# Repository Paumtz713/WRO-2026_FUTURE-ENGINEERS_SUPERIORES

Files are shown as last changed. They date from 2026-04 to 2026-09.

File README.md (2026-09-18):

# WRO 2026 Future Engineers Superiores
<p align="center">
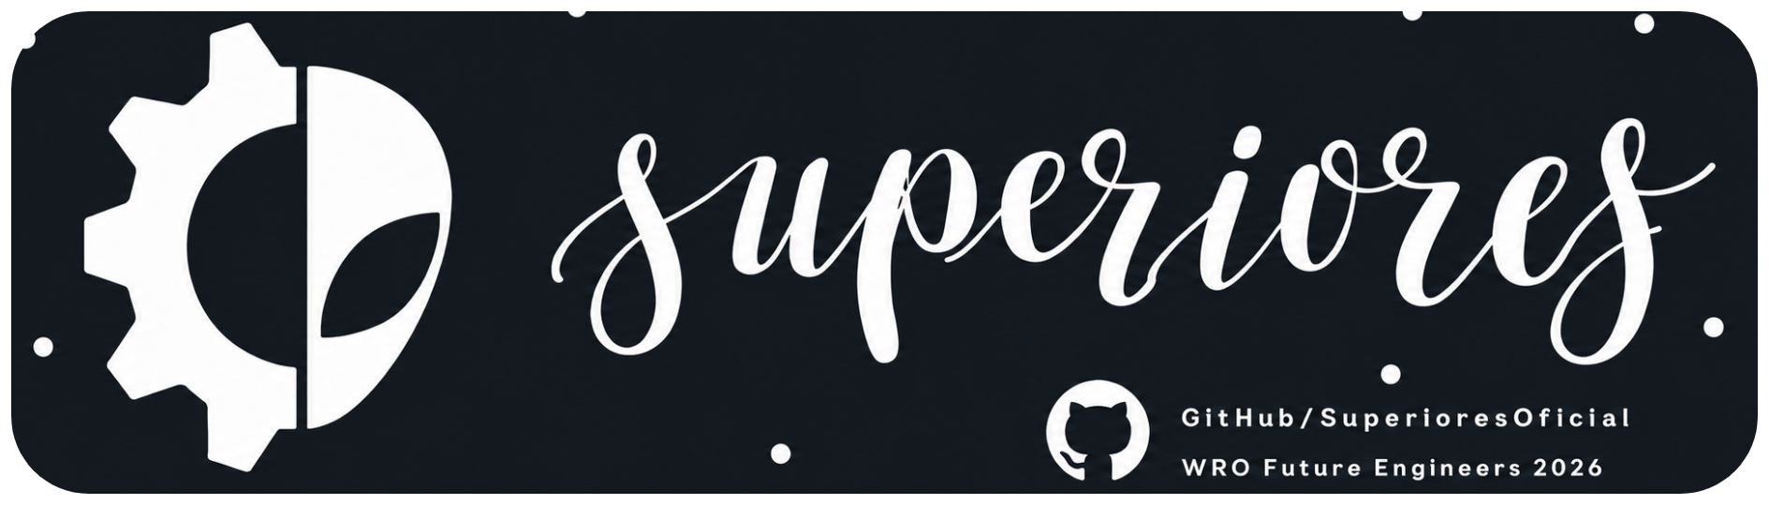
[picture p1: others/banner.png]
SUPERIORES
  
</p>

> [!NOTE]
> **Documentation Migration Notice**
> Due to an issue locating the main repository during the initial development phase, previous documentation and progress updates were temporarily tracked in a secondary repository. You can review the prior commits and documentation at the following link:
> https://github.com/daiilvvyeyo/WRO-2026-Future-Engineers-Superiores

<p align="center"> <a href="https://www.facebook.com/share/19RiiDTZch/"> Facebook </a> &nbsp;&nbsp;&nbsp; <a href="https://www.instagram.com/losgrisesrt/"> Instagram </a> &nbsp;&nbsp;&nbsp; <a href="https://www.tiktok.com/@losgrisesrobotics"> TikTok </a> </p>

## Team Members

#### Team photo

<p align="center">
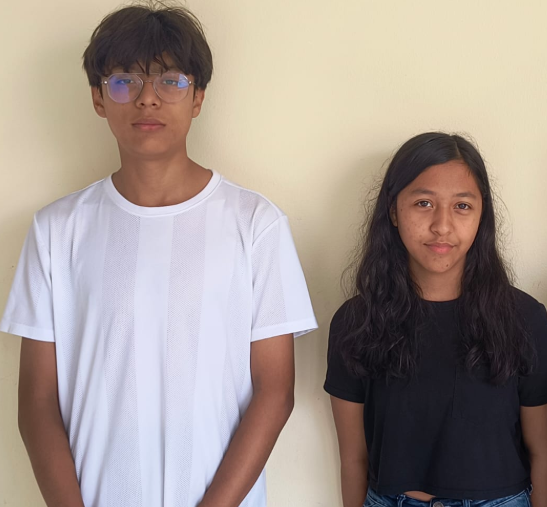
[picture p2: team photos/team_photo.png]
Foto de equipo
  
</p>

<table align="center">
  <tr>
    <th colspan="2" align="left">
      Eduardo Alvarado González — Coach & Founder
    </th>
  </tr>
  <tr>
    <td width="260">
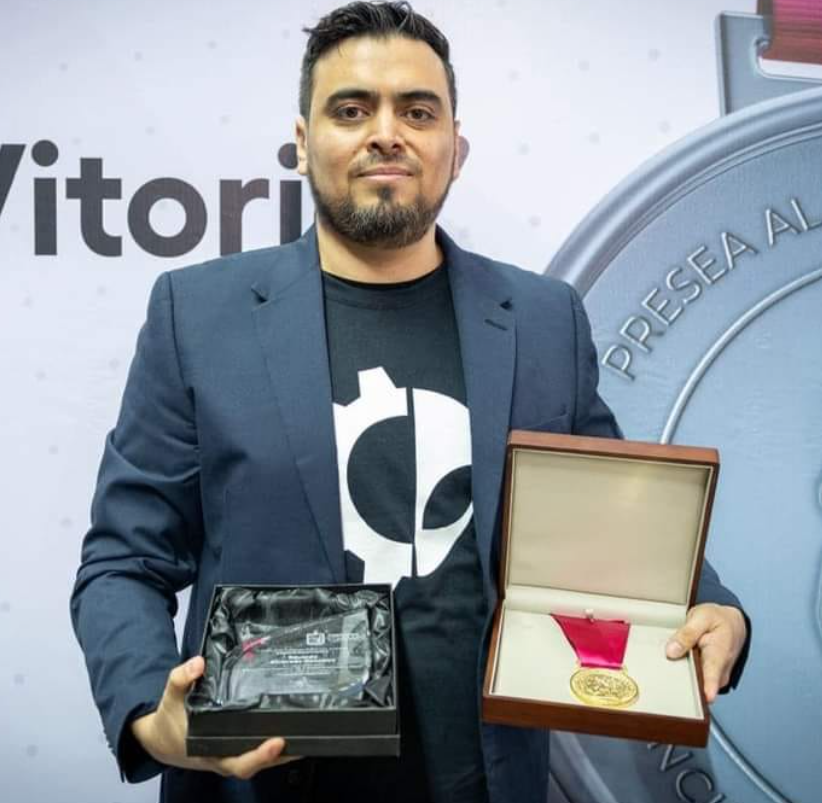
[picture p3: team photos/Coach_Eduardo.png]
      
    </td>
    <td>
      <b>Age:</b> 40<br><br>
      I founded <b>Los Grises Superiores</b> in 2014 with the goal of creating a team where students could learn engineering through real competition experience. Over the years we have participated in multiple WRO and TMR events, reaching both national and international stages. This season I mainly support the team in project organization, technical guidance, and helping the students improve their engineering process during development.
    </td>
  </tr>
</table>

---

<table align="center">
  <tr>
    <th colspan="2" align="left">
      Christopher Pérez Cortés — Programming & Electronics
    </th>
  </tr>
  <tr>
    <td width="260">
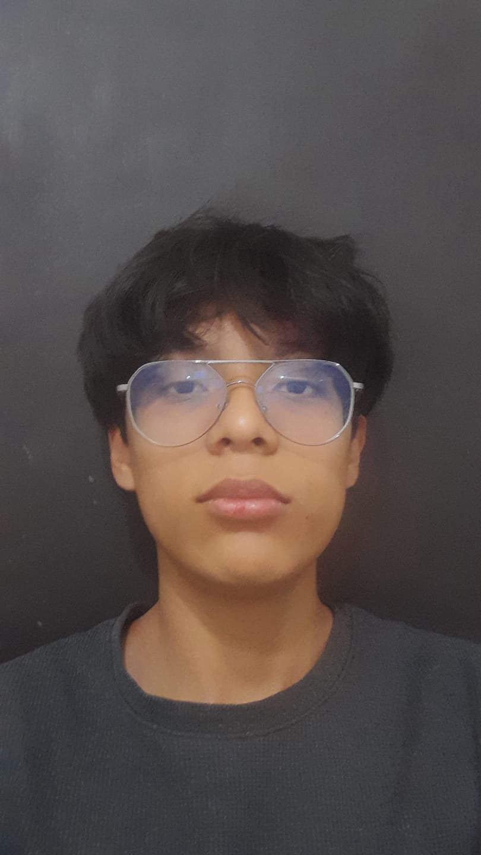
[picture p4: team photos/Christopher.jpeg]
      
    </td>
    <td>
      <b>Age:</b> 14<br><br>
      I joined the robotics club this year after taking an intensive robotics course, and since then I have been learning a lot about electronics, Arduino programming, and 3D design in Onshape. In the team I mainly work on the robot code, sensor integration, and electronics. WRO 2026 is my first international robotics competition, so this season has been a big learning experience for me.
    </td>
  </tr>
</table>

---

<table align="center">
  <tr>
    <th colspan="2" align="left">
      Bárbara Daiana García Balboa — Design & Assembly
    </th>
  </tr>
  <tr>
    <td width="260">
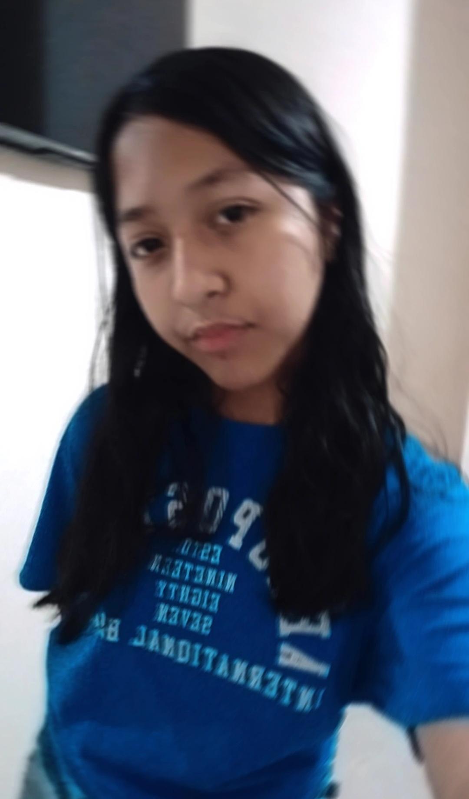
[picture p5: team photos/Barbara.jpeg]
      
    </td>
    <td>
      <b>Age:</b> 13<br><br>
      I joined the robotics club a few months ago after completing two robotics courses. My main role in the team is helping with the mechanical design, chassis assembly, and testing different structural ideas for the robot. This is my first robotics competition, so I have been learning how the engineering and competition process works while building the project together as a team.
    </td>
  </tr>
</table>

##  Track Challenges

* **Open Challenge:** Complete 3 full laps of the track in the shortest time possible while maintaining lane alignment using sensors (distance and vision).
* **Obstacle Challenge:** Navigate the track and dodge colored pillars in real time using computer vision (camera):
  * **Red Pillars:** Dodge by passing on the right.
  * **Green Pillars:** Dodge by passing on the left.
* **Autonomous Parking:** Detect the designated parking space and perform an automatic parallel parking maneuver upon completion.

## Project Videos

The following videos show the vehicle driving autonomously during both WRO Future Engineers 2026 challenges. Additional video documentation is available in the [video/](video/) folder.

<table>
  <tr>
    <th>Open Challenge</th>
    <th>Obstacle Challenge</th>
  </tr>
  <tr>
    <td align="center">
      <a href="https://www.youtube.com/watch?v=diX7vBUeAKw">
        
      </a>
    </td>
    <td align="center">
      <a href="https://www.youtube.com/watch?v=LjnSCSj2Bsk">
        
      </a>
    </td>
  </tr>
  <tr>
    <td align="center">
      <a href="https://www.youtube.com/watch?v=diX7vBUeAKw">Watch on YouTube</a>
    </td>
    <td align="center">
      <a href="https://www.youtube.com/watch?v=LjnSCSj2Bsk">Watch on YouTube</a>
    </td>
  </tr>
</table>

## Project Overview & Abstract

This project was developed as the evolution of our 2025 WRO Future Engineers robot, which successfully reached the international final. Based on the experience gained during that season, the entire vehicle was redesigned for 2026 using a fully 3D-printed chassis, an OpenMV H7 camera, and an Arduino Nano-based control system to improve stability, adaptability, and overall performance.

The robot was built to autonomously complete the two Future Engineers challenges established by the WRO 2026 rules. During the Open Challenge, the vehicle must complete three laps while adapting to randomized track conditions such as driving direction, starting position, and corridor width. In the Obstacle Challenge, the robot must detect colored traffic pillars, avoid them from the correct side, and finally perform a parallel parking maneuver inside the designated parking zone.

Throughout the development process, the team continuously tested and improved both the mechanical and software systems in order to adapt the robot to the new 2026 rule changes and achieve more reliable autonomous behavior.

### Chassis Design & Iteration 

Our first robot designs were based on a LEGO Mindstorms EV3 chassis. While it was easy to build and modify, we noticed several limitations during testing, especially related to weight, space distribution, and steering precision. The EV3 structure was also too restrictive for the type of custom design we wanted to achieve for the 2026 season.

Because of this, we decided to redesign the entire chassis using fully 3D-printed parts designed in Onshape. Our main goal was to create a lighter and more compact structure while still following the WRO size and weight regulations. We also wanted to improve stability, steering performance, and sensor placement.

Throughout the season, we tested different chassis versions. The first prototype used a flat structure, but during steering tests we discovered that the chassis flexed when the servo applied force, causing inaccurate steering movements. To improve rigidity, we redesigned the structure by adding reinforced supports and increasing the wall thickness in critical areas.

Later, we developed a third version focused on improving cornering performance in the new 600 mm corridor introduced in the 2026 rules. We reduced the overall length of the robot and relocated some electronic components to lower the center of gravity and improve balance while turning.

During the final reprint of the chassis using grey PLA filament, we encountered an unexpected problem: the drivetrain became stuck even though the motor was working correctly. After inspecting the structure, we realized that the new filament produced slightly tighter tolerances, causing friction around the rear axle housing. To solve this, we manually sanded the affected area until the shaft rotated smoothly again. After this issue, we started checking all moving parts after every print before assembling the robot.

### Steering System

The robot uses an **Ackermann steering geometry** controlled by a rack-and-pinion mechanism. The steering system was developed through several iterations during the prototyping process.

In the previous prototype, we used a **Steren MOT-110 micro servo** to control the steering mechanism. This version allowed us to test the basic steering geometry and evaluate the mechanical response of the system.

For the final vehicle, we decided to use an **SG90 micro servo**. The SG90 was selected for the final version because it provided the required steering movement while being compact and easy to integrate into the redesigned chassis.

The servo is connected to a **LEGO Technic rack-and-pinion mechanism (part 64781)**, which converts the servo's rotational movement into the linear movement required to turn the front wheels.

The steering system follows **Ackermann geometry**, allowing the inner and outer front wheels to turn at different angles during a corner. This helps the vehicle maintain a more appropriate trajectory while navigating the track.

The final steering configuration consists of:

* **Servo motor:** SG90 micro servo
* **Steering mechanism:** Rack-and-pinion
* **Rack:** LEGO Technic part 64781
* **Steering geometry:** Ackermann
* **Control:** Arduino Nano

 ## Robot Photos

| Front | Back | Left |
|:---:|:---:|:---:|
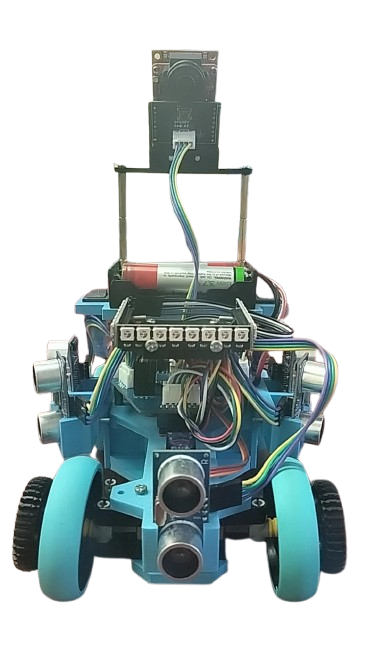
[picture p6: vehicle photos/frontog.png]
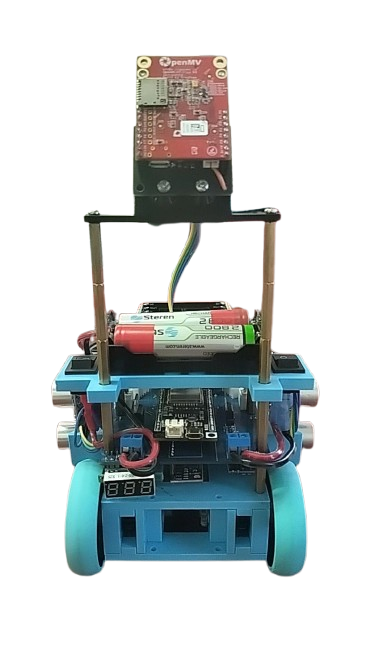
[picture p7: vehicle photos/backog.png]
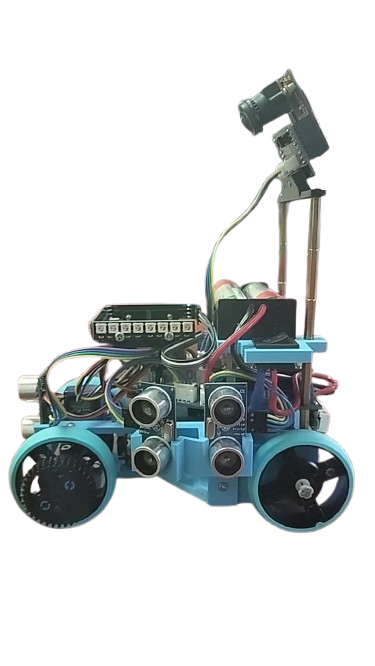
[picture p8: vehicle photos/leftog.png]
|  |  |  |

| Right | Top | Bottom |
|:---:|:---:|:---:|
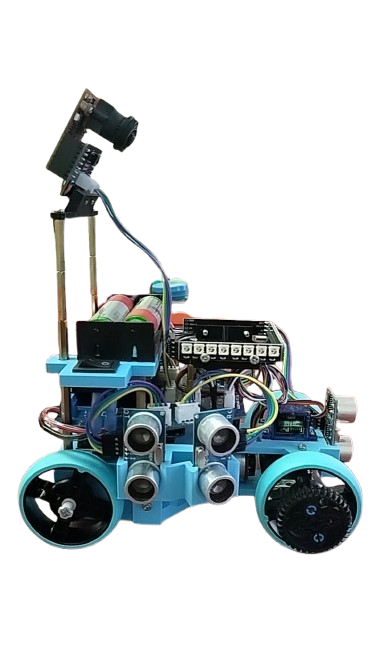
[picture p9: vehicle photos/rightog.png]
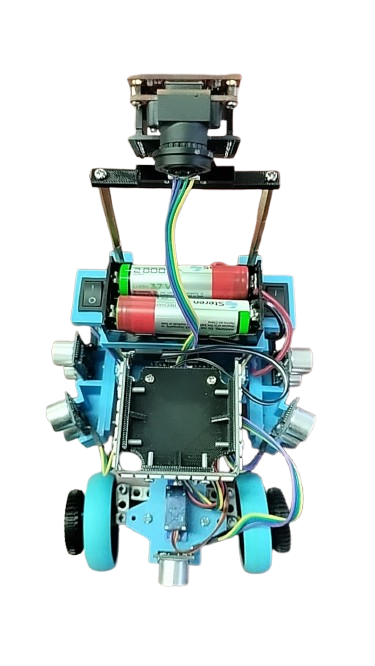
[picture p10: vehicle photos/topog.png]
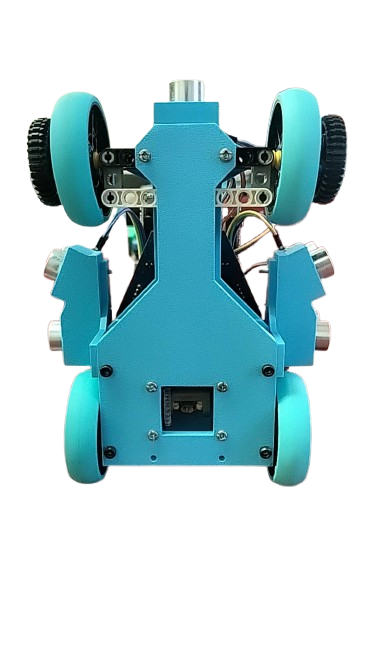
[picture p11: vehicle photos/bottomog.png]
|  |  |  |

- Robot Weight: 0.710 kg

## Robot 360º

<p align="center">
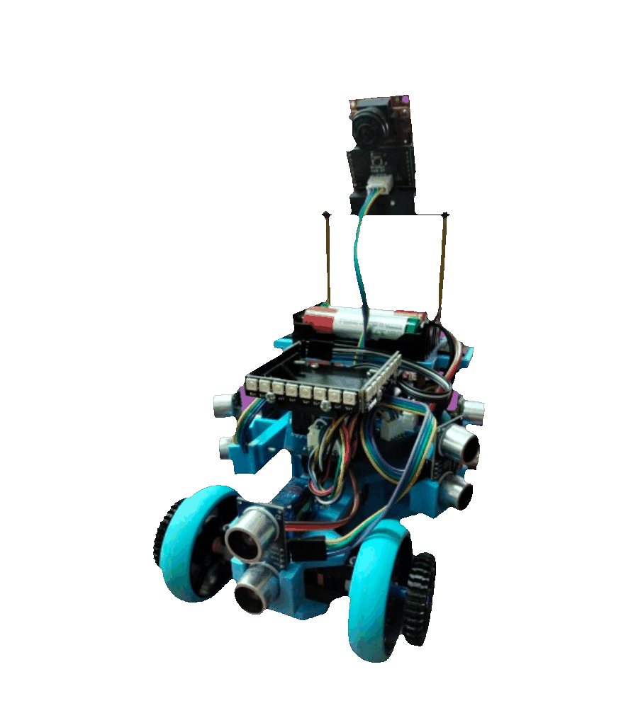
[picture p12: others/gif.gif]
Robot 360º
  
</p>

## Robot Components

| Component | Quantity | Main Function |
|---|:---:|---|
| ESP32 Microcontroller | 1 | Main processing / communication with OpenMV and sensors |
| Arduino Nano Microcontroller | 1 | Additional control (motor, encoders, ultrasonic sensors) |
| OpenMV Camera | 1 | Color vision, RX/TX communication (UART) |
| BNO085 IMU | 1 | Orientation / yaw (I2C: SCL, SDA) |
| HC-SR04 Ultrasonic Sensor | 5 | Distance measurement (front, 2 left, 2 right) |
| TB6612FNG Motor Driver | 1 | H-bridge for controlling the DC motor (PWMA, AIN1, AIN2, STBY) |
| DC Motor with Encoder | 1 | Traction (uses ENC_A and ENC_B for speed feedback) |
| 4-Channel Logic Level Converter | 1 | Adapts 3.3V ↔ 5V signals between modules (HV/LV x4) |
| Steering Servo | 1 | Steering control (S1 signal, SER_5+ power supply) |
| NeoPixel LEDs (WS2812) | 1 strip | Indicator lighting / vision assistance |
| 18650 Battery | Several | Main power supply (power bank) |
| Mini-560 Buck Converter | 2 | Voltage regulation (one line to 5V, another to 3.3V) |
| 7805 Voltage Regulator | 2 | One for the servo (SER_5+), another for the LEDs (LEDS_5+) |
| Digital Voltmeter | 1 | Battery voltage monitoring |

## Code

Our robot uses two main programs that work together. The Arduino Nano handles the distance sensors and LED strips, while the ESP32 acts as the main controller of the robot.

### Sensor Codes

- [ESP32 Open Optimized](./ESP32_Open_Optimizado.ino) — Main control code that processes the sensor data and manages the robot's movement.

- [Nano Sensors I2C 3x8](./Nano_Sensors_I2C_3x8.ino) — Reads the ultrasonic sensors through I2C and sends distance measurements to the ESP32.

- [Obstacle & Parking Exit](./OBSTACULOS_Salida_del_parking.ino) — Controls obstacle detection and the sequence used to exit the initial parking area.
### Arduino Nano — Sensors & LEDs

The Arduino Nano works as an assistant to the ESP32. It measures the five ultrasonic sensors, controls three strips of eight LEDs, and communicates the sensor measurements to the ESP32 through I2C.

### OpenMV – Detección y visión

[Detección de pilares, parking y obstáculos](./codes/color_corner_v6.py)  
Sistema de visión de la OpenMV encargado de detectar pilares rojos y verdes, identificar las paredes y el hueco del estacionamiento, detectar posibles colisiones y enviar los datos al ESP32 mediante UART. :contentReference[oaicite:0]{index=0}

[Explicación del código](./codes/Pegado%20text(1).txt)  
Explicación detallada del funcionamiento del sistema de visión, sus ROI, filtros de color y forma, detección del parking y comunicación con el ESP32. :contentReference[oaicite:1]{index=1}

**Main functions:**

* Reads five ultrasonic distance sensors.
* Controls 24 LEDs arranged in three strips of eight.
* Sends distance measurements to the ESP32.
* Receives the LED intensity level from the ESP32.
* Uses I2C communication at address `0x08`.

[View Arduino Nano Code](./codes/Nano_Sensores_I2C_3x8.ino)

### ESP32 — Main Robot Control

The ESP32 is the main controller of the robot. It receives the distance measurements from the Arduino Nano and uses them to control the motor, steering, speed, safety systems, lap counting, and final parking sequence.

**Main functions:**

* Receives data from the five distance sensors.
* Controls the DC motor through the TB6612FNG.
* Controls the SG90 steering servo.
* Uses the BNO085 to track orientation and count three laps.
* Uses the encoder to detect actual wheel movement.
* Maintains the robot centered using PID control.
* Detects walls and corners.
* Adjusts speed according to track conditions.
* Performs emergency reverse maneuvers.
* Executes the final movement after completing three laps.
* Provides an optional Wi-Fi dashboard for monitoring the robot.

[View ESP32 Code](./codes/ESP32_Open_Optimizado.ino)

# LEGO Set Use

| BLItemNo | ElementId | LdrawId | Part Name | BLColorId | LDrawColorId | Color Name | Qty | Weight (g) | Price per piece (USD) | Total (USD) |
|---|---|---|---|---|---|---|-----|---|---|---|
| 6589 | 4565452 | 6589.dat | Technic Gear 12 Tooth Bevel | 19 | 19 | Tan | 3 | 0.40 | 0.15 | 0.45 |
| 3713 | 6275844 | 3713.dat | Technic Bush | 86 | 7 | Light Bluish Gray | 6 | 0.20 | 0.05 | 0.30 |
| 32523 | 4142822 | 32523.dat | Technic Liftarm 1 x 3 | 11 | 0 | Black | 2 | 0.80 | 0.20 | 0.40 |
| 39367pb01 | 6460453 | 39367.dat | Wheel 56 x 14 Technic | 102 | 9 | Blue | 4 | 5.50 | 1.50 | 6.00 |
| 62821b | — | 62821.dat | Technic Differential Gear (Closed) | 85 | 8 | Dark Bluish Gray | 1 | 3.50 | 3.50 | 3.50 |
| 87083 | 6083620 | 87083.dat | Technic Axle 4L with Stop | 85 | 8 | Dark Bluish Gray | 4 | 0.60 | 0.10 | 0.40 |
| 94925 | 4640536 | 94925.dat | Technic Gear 16 Tooth | 86 | 7 | Light Bluish Gray | 4 | 0.50 | 0.20 | 0.80 |
| 43093 | — | 43093.dat | Technic Axle 1L with Pin | 102 | 9 | Blue | 2 | 0.30 | 0.15 | 0.30 |
| 43093 | — | 43093.dat | Technic Axle 1L with Pin | 19 | 19 | Tan | 2 | 0.30 | 0.15 | 0.30 |
| 48989 | 6282158 | 48989.dat | Technic Pin Connector Perpendicular 3L | 86 | 7 | Light Bluish Gray | 2 | 1.00 | 0.30 | 0.60 |
| 40490 | 4645732 | 40490.dat | Technic Liftarm 1 x 9 | 15 | 15 | White | 1 | 1.20 | 0.50 | 0.50 |
| 32523 | 4142822 | 32523.dat | Technic Liftarm 1 x 3 | 11 | 0 | Black | 2 | 0.80 | 0.20 | 0.40 |
| 4265c | 6271167 | 4265c.dat | Technic Bush 1/2 Smooth | 3 | 14 | Yellow | 2 | 0.10 | 0.10 | 0.20 |

| TOTAL PARTS | TOTAL WEIGHT |
|---|---|
| 35 | 39.2 g |

### Traction System

For the traction system, we decided to use a rear-wheel drive configuration powered by a DC motor with an integrated gearbox connected to a TB6612FNG motor driver. Both rear wheels are connected through the same drivetrain, which helped us keep the system simpler, lighter, and fully compliant with the WRO rules.

During testing, we experimented with different gear ratios to find the best balance between speed and control. Some configurations made the robot extremely fast, but that also reduced the reaction time when detecting obstacles or correcting direction. Other configurations improved stability but made the robot too slow during acceleration.

After multiple test sessions, we found that an approximate 1:30 gear ratio gave us the best overall performance for both challenges.

| Parameter | Value |
|---|---|
| Drive motor | DC motor with gearbox |
| Motor driver | TB6612FNG dual H-bridge |
| Drive system | Rear-wheel drive |
| Wheel configuration | Both rear wheels connected together |
| Selected gear ratio | Approx. 1:30 |

### Speed Testing

| PWM Value | Approx. Speed | Main Use |
|---|---|---|
| 110 | ~0.28 m/s | Narrow corridor and obstacle sections |
| 130 | ~0.36 m/s | Normal track navigation |
| 150 | ~0.44 m/s | Open straight sections |

### Gear Ratio Comparison

| Gear Ratio | What Happened |
|---|---|
| 1:20 | The robot became too fast and reacted late to obstacles |
| 1:50 | Acceleration became too slow for completing laps efficiently |
| 1:30 | Best balance between speed, control, and stability |

#### Mechanical Trade-offs & Decisions

During the development process, we tested different ideas and components before deciding on the final configuration of the robot. In several cases, we had to choose between simplicity, performance, reliability, and compliance with the WRO rules.

| System | Option We Chose | Option We Rejected | Why We Chose It |
|---|---|---|---|
| Chassis material | 3D-printed PLA | LEGO Technic | Allowed us to create custom shapes while reducing overall weight |
| Steering system | Servo + rack mechanism | Differential steering | More stable and compliant with WRO steering rules |
| Drive system | Single DC motor | Two coupled motors | Simpler wiring, lighter structure, and easier control |
| Vision system | OpenMV H7 (UART) | HuskyLens (I2C) | OpenMV provided faster and more stable data during movement |

One of the most important decisions was replacing the HuskyLens camera with the OpenMV H7. During testing, we noticed that the HuskyLens sometimes sent data too slowly, which caused unstable steering corrections and servo oscillation. After switching back to the OpenMV system, the robot behaved much more smoothly and consistently during autonomous navigation.**

## Final Robot Design

<p align="center">
  <a href="./models/final_design.stl">
    Final 3D Design of Superiores Robot
  </a>
</p>

<p align="center">
  <b>Final 3D chassis design — WRO 2026 Future Engineers</b><br>
  Click the image to open the complete STL model.
</p>

### Why We Chose This Design

The final chassis was selected after several mechanical iterations and testing sessions throughout the development of our WRO 2026 robot.

Our first prototypes were based on LEGO Technic and EV3 components. Although this approach made early modifications easier, it introduced several limitations, including higher weight, less freedom in component placement, chassis flex, and a larger overall structure.

For the final version, we designed a custom 3D-printed chassis in Onshape. This allowed us to control the geometry of the robot and place each mechanical and electronic component according to its function.

The final design was chosen mainly for the following reasons:

- **Compact dimensions:** A shorter chassis improves maneuverability and reduces the turning radius, which is especially important in the narrower sections of the WRO 2026 track.

- **Improved steering rigidity:** Earlier versions flexed when the steering servo applied force. The final chassis includes reinforced structural areas to reduce deformation and make the Ackermann steering system more precise.

- **Better component distribution:** The ESP32, Arduino Nano, motor driver, batteries, OpenMV camera, ultrasonic sensors, BNO085 and other electronics can be positioned in specific locations instead of being limited by a LEGO structure.

- **Lower center of gravity:** Heavy components were positioned as low as possible to improve stability while turning and during obstacle avoidance maneuvers.

- **Sensor positioning:** The custom structure provides dedicated mounting positions for the front and lateral ultrasonic sensors, allowing the robot to measure the walls and obstacles from consistent angles.

- **Camera visibility:** The front section was designed so the OpenMV camera has a clear field of view for detecting red and green pillars as well as the parking area.

- **Ackermann steering integration:** The chassis was designed around the steering mechanism instead of adapting the steering mechanism to an existing chassis. This provides better alignment between the servo, rack-and-pinion system and front wheels.

- **Rear-wheel-drive integration:** The rear section provides the necessary space and alignment for the DC motor, drivetrain and rear axle while keeping the propulsion system compact.

- **Easy maintenance:** The open and modular structure allows us to access the electronics, sensors and mechanical components quickly during testing and competition.

- **Iterative manufacturing:** Because the chassis is 3D printed, individual parts can be redesigned and reprinted when a problem is discovered without rebuilding the entire robot.

The objective of the final design was not simply to make the robot smaller or lighter. We wanted the mechanical structure, electronics, sensors and software to work together as a single system.

This design represents the lessons learned from our previous prototypes and provides a better balance between **stability, maneuverability, sensor coverage, steering precision, accessibility and reliability** for the WRO 2026 Future Engineers challenges.

### 3D Model

The complete printable model is available here:

 **[Open `final_design.stl`](./models/final_design.stl)**

####  Structural Components (3D Design) 

<div align="center">

| Central Sensor Mount | Side Sensor Mounts | Rear Support |
|:--:|:--:|:--:|
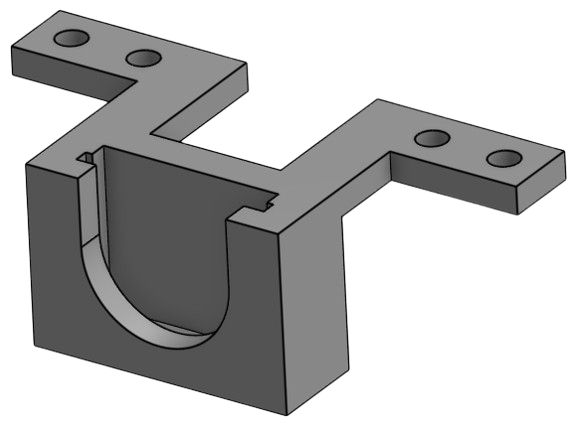
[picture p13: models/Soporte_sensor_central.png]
Central Sensor Mount
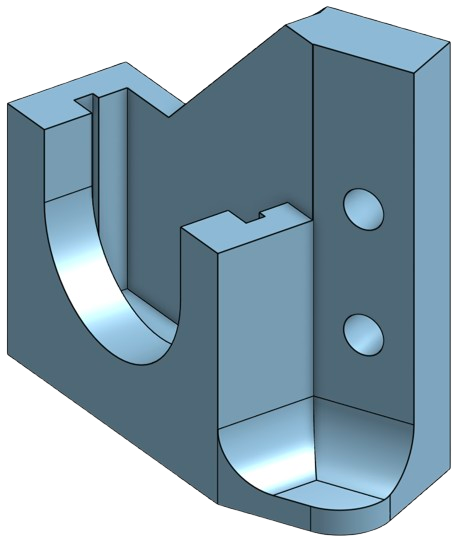
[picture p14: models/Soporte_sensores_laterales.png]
Side Sensor Mounts
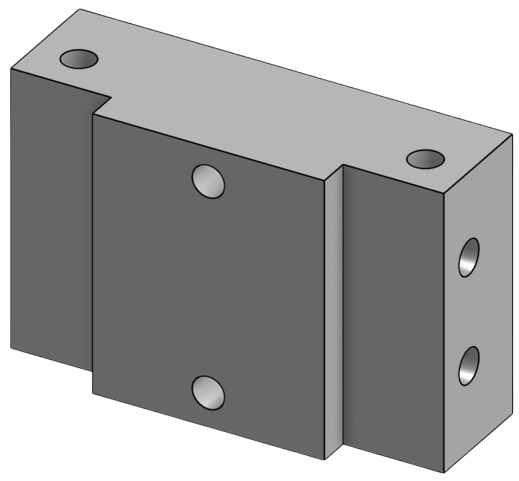
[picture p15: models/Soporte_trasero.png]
Rear Support
|  |  |  |

| External Supports | Internal Supports | Directional Module |
|:--:|:--:|:--:|
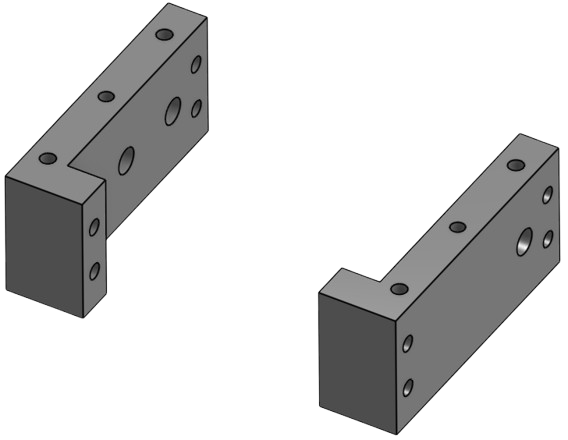
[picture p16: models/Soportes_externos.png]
External Supports
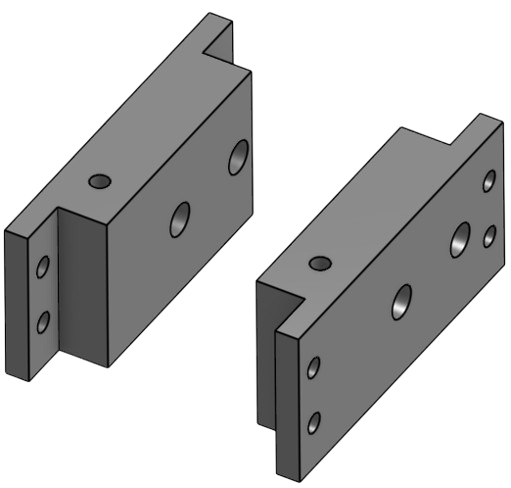
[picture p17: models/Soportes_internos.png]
Internal Supports
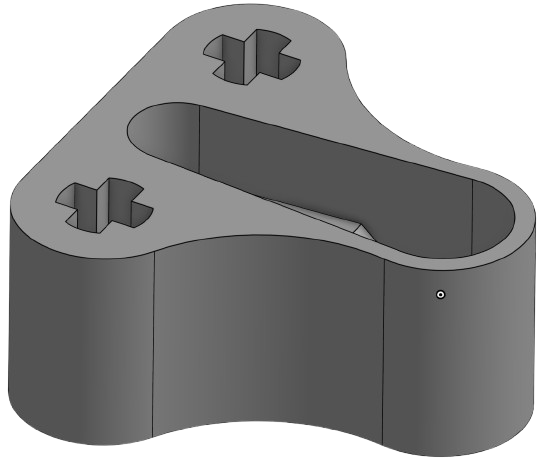
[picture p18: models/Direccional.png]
Directional Module
|  |  |  |

| Lower Body | Upper Body | Full Base Structure |
|:--:|:--:|:--:|
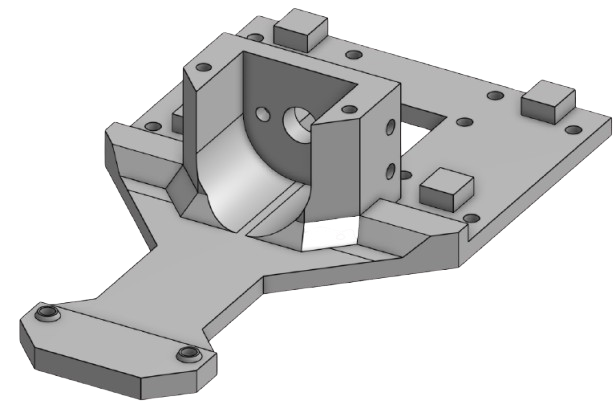
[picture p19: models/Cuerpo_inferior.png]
Lower Body
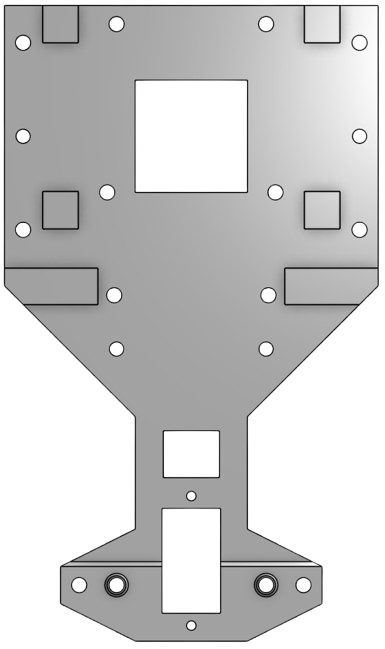
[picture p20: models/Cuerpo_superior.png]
Upper Body
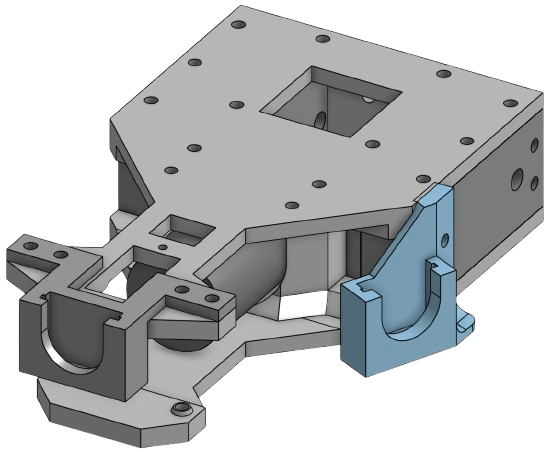
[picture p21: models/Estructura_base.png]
Full Base Structure
|  |  |  |

</div>

---

| Main Switch | 1 | Motor / system power cutoff |
| 2P Terminal Block | 1 | Power input (7.4V+) |

####  Main Chassis Structure

<div align="center">

| Lower Body | Upper Body |
|:--:|:--:|
|  |  |

</div>
---

####  Complete Aseembly

<div align="center">

| Full Base Structure |
|:--:|
|  |

</div>

---

####  Steering Component

<div align="center">

| Directional Module |
|:--:|
|  |

</div>
---

## PCB & Wiring Implementation

<table>
  <tr>
    <td align="center" width="50%">
      <strong>PCB Design</strong><br><br>
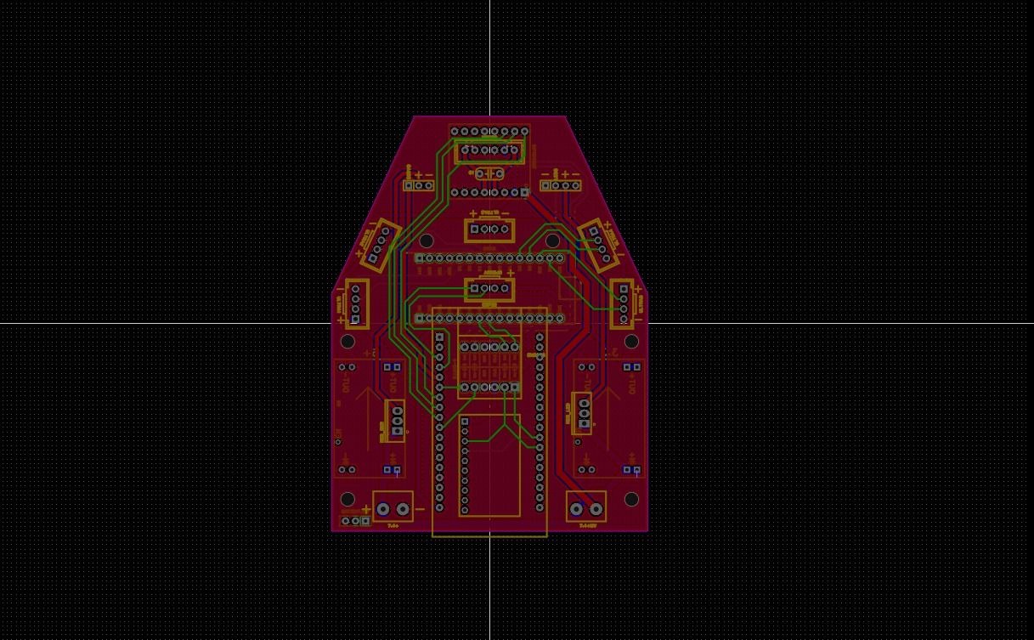
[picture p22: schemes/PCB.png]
      
    </td>
    <td align="center" width="50%">
      <strong>Real PCB</strong><br><br>
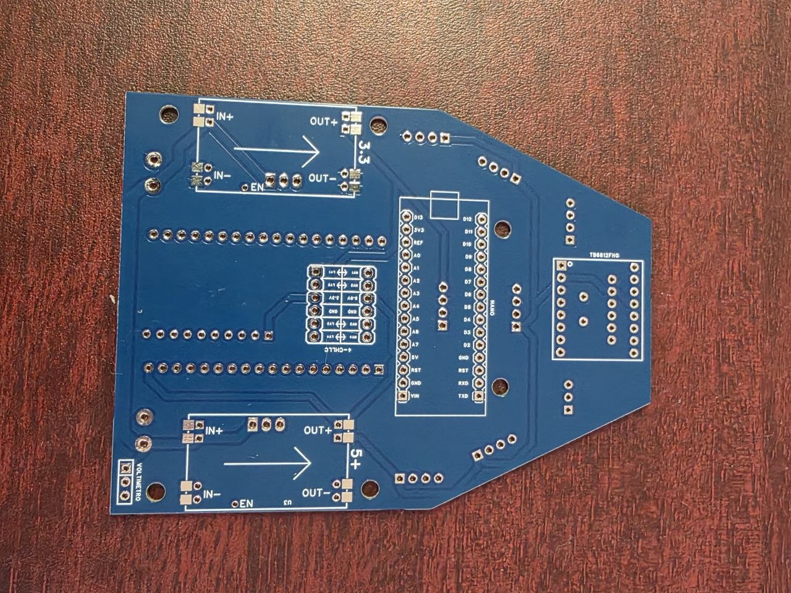
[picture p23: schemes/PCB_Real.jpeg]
      
    </td>
  </tr>
  <tr>
    <td colspan="2" align="center">
      <strong>PCB Schematic</strong><br><br>
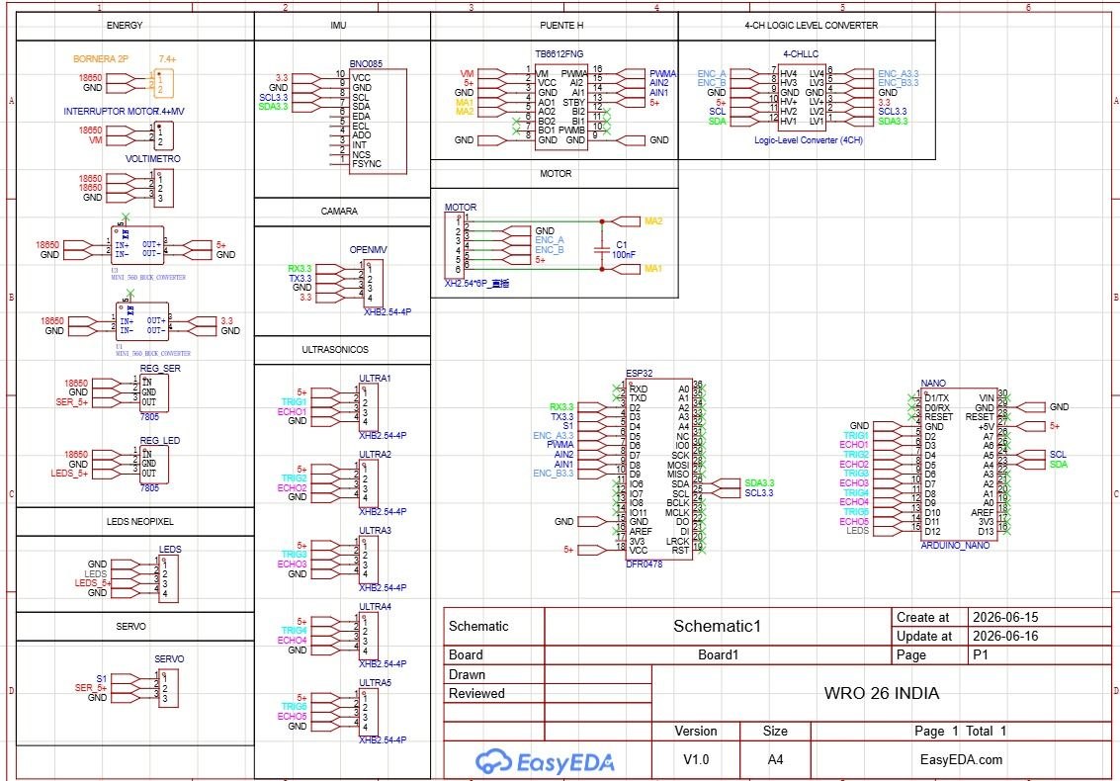
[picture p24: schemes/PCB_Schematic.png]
      
    </td>
  </tr>
</table>

## Source Code

Full source code available in `src/`

Our robot is controlled using an Arduino Nano, where we manage sensor reading, steering control, obstacle reactions, and movement decisions. Throughout the season, we continuously tested and adjusted the code to improve stability and response time during both challenges.

Some of the main functions implemented in our code include:

- Ultrasonic-based wall navigation
- IMU yaw tracking and lap counting
- OpenMV color detection for red and green pillars
- Obstacle avoidance logic
- Parking sequence development

# Criterion 2 — Power & Sensor Architecture

## Power System & Budget

To power the robot, we use two Steren Li-ion 3.7V batteries connected in series, providing a total of 7.4V. We separated the power system into two rails: one dedicated to the electronic components and another one for the motor system. This helped us reduce electrical noise and achieve more stable sensor readings during movement.

| Rail | Components Powered | Estimated Consumption |
|---|---|---|
| 5V Logic Rail | Arduino Nano, MPU6050, OpenMV H7, HC-SR04 sensors | ~600 mA |
| Motor Rail | TB6612FNG + DC motor | ~1.5 A |

We used a Mini 560 step-down regulator to provide a stable 5V supply for the electronic components. During testing, this configuration proved reliable even when the motor rapidly changed speed.

One issue we considered was battery voltage drop during long testing sessions. When the voltage became too low, the robot started losing motor performance and sensor stability. Because of this, we added a small digital voltmeter directly on the chassis to monitor battery voltage before every run.

## Ultrasonic Sensor Expansion

During early testing with 3 sensors, we noticed that the robot couldn't measure distances accurately enough to maintain precise wall centering. To solve this and improve spatial awareness, we upgraded our setup to 5 HC-SR04 ultrasonic sensors: 2 on the right side, 2 on the left side, and 1 in the front center.

| Sensor | Position | Purpose |
| --- | --- | --- |
| Front | Front center | Detect walls and corners ahead |
| Left (×2) | Left side | Measure distance and alignment to left wall |
| Right (×2) | Right side | Measure distance and alignment to right wall |
### Power Consumption

| Component | Approx. Current |
|---|---|
| Arduino Nano | 20 mA |
| MPU6050 | 3.9 mA |
| OpenMV H7 | ~280 mA |
| HC-SR04 ×5 | ~75 mA |
| Steering Servo | ~200 mA |
| DC Motor | 800–1500 mA |

## Wiring Diagram

Full wiring diagrams available in `schemes/`

The electrical system was designed to keep the wiring as organized and compact as possible inside the chassis. Most components are connected directly to the Arduino Nano and distributed through the PCB designed by the team.

### Main Connections

| Component | Connection |
|---|---|
| MPU6050 | SDA → A4 / SCL → A5 |
| OpenMV H7 | UART TX/RX |
| Front Ultrasonic | TRIG → D7 / ECHO → D6 |
| Left Ultrasonic | TRIG → D3 / ECHO → D2 |
| Right Ultrasonic | TRIG → D5 / ECHO → D4 |
| DC Motor Driver | AIN1 → D10 / AIN2 → D11 / PWMA → D9 |
| Steering Servo | Signal → D8 |

The MPU6050 communicates through I2C, while the OpenMV camera uses UART communication. This allowed us to keep the I2C bus dedicated only to the IMU and helped improve communication stability between modules.

## PCB & Iteration Problems

To keep the internal wiring cleaner and more organized, we designed a custom PCB to centralize all the electrical connections inside the robot. Compared to direct wiring, this helped us reduce cable clutter, simplify debugging, and improve overall reliability during movement.

During one of our testing sessions, we accidentally inserted the batteries backward into the power rail. This reverse polarity connection caused the Li-ion battery to short-circuit and emit smoke due to thermal overload. 

Fortunately, none of our main sensors or microcontrollers suffered permanent damage. However, to prevent potential trace degradation or instability in the power lines, we solved this issue by replacing the damaged board with a spare custom PCB we already had available.

Additionally, during our first PCB assembly, excess solder created small bridges between nearby PCB traces, causing interference between the TRIG and ECHO signals of the sensors. We solved this by removing the excess solder with desoldering braid and re-soldering the affected areas. Once cleaned, the readings stabilized completely.

## Sensor Selection & Placement

### HC-SR04 Ultrasonic Sensors

During early testing with 3 sensors, we noticed that the robot couldn't measure distances accurately enough to maintain precise wall centering. To solve this and improve spatial awareness, we upgraded our setup to 5 HC-SR04 ultrasonic sensors: 2 on the right side, 2 on the left side, and 1 in the front center.

| Sensor | Position | Purpose |
| --- | --- | --- |
| Front | Front center | Detect walls and corners ahead |
| Left (×2) | Left side | Measure distance and alignment to left wall |
| Right (×2) | Right side | Measure distance and alignment to right wall |

### MPU6050 IMU

The MPU6050 is used mainly for yaw tracking and orientation correction. We use the gyroscope data to count turns, detect drift, and calculate completed laps during autonomous navigation.

Some of the main functions of the IMU in our robot are:

- Counting 90° turns
- Correcting drift on straight sections
- Determining lap completion through accumulated yaw

Before every run, the robot performs a short calibration process while remaining completely still. This allows the IMU to calculate sensor offsets and improve accuracy during movement.

### Camera — OpenMV H7

For vision processing, we currently use an OpenMV H7 camera connected through UART communication.

| Parameter | Value |
|---|---|
| Resolution | 320 × 240 px |
| Communication | UART (115200 baud) |
| Detection Mode | Color blob tracking |
| Objects Detected | Red and green pillars |
| Frame Rate | ~30 FPS |
| Camera Position | Front-center, tilted downward |

At the beginning of the season, we originally planned to use a HuskyLens camera because it was easier to integrate and already included built-in object detection features. However, during testing we discovered that the HuskyLens was sending data too slowly for our steering system.

Because the Arduino was not receiving continuous detection updates, the steering servo started oscillating and the robot moved inconsistently during straight sections.

To solve this problem, we switched back to the OpenMV H7 platform that we had already used during the 2025 season. Using a custom MicroPython script, the OpenMV continuously sends detection data to the Arduino through UART communication, resulting in much smoother and more stable steering behavior.

Although the OpenMV required more programming and communication handling, the improvement in reliability and response time made the change completely worth it.

After several tests, we also found that mounting the camera with a slight downward angle produced the best detection results without capturing too much of the floor or reducing detection range.

## Calibration Methods

Before testing or competing, we calibrate different parts of the robot to make sure everything works consistently on the track.

| Component | How We Calibrate It | When |
|---|---|---|
| MPU6050 | Using `calcOffsets()` while the robot stays still | Before every run |
| OpenMV H7 | Adjusting LAB color thresholds in OpenMV IDE | Before testing and competitions |
| HC-SR04 Sensors | Comparing readings with real measured distances | During testing |
| Steering Servo | Adjusting the steering center value manually | After rebuilding or modifying the chassis |

These calibration steps helped us improve steering accuracy, sensor stability, and overall consistency during autonomous runs.

# Criterion 3 — Software Architecture & Obstacle Strategy

## System Overview

Our entire control system runs on a single Arduino Nano. All the sensor reading, steering corrections, obstacle detection, and movement decisions happen inside the same main loop.

Instead of using multiple processors, we decided to keep everything on one controller because it made the robot easier to debug, modify, and test throughout the season. After several iterations, this setup gave us stable performance and fast enough response times for both challenges.

To keep the code organized, we divided the program into different modules.

| Module | Main Functions | What It Does |
|---|---|---|
| IMU | `actualizarIMU()` | Tracks robot rotation and yaw |
| Ultrasonics | `medirDistancia()` | Measures wall distances |
| Lateral Control | Steering correction logic | Keeps the robot centered |
| OpenMV | `parseOpenMV()` | Receives obstacle detection data |
| Drive | `avanzar()`, `girarSuave()` | Controls movement and steering |
| Start Sequence | `faseInicio` | Handles startup alignment |

## State Machine

To organize the robot behavior, we created different operating states depending on what the robot detects during the run.

| State | Purpose |
|---|---|
| START | Initial alignment before moving |
| LANE_FOLLOW | Normal navigation and wall following |
| AVOID_COLOR | Obstacle avoidance using camera detection |
| EMERGENCY | Collision prevention and recovery |
| STOP | End of the run after completing laps |

The robot constantly switches between these states depending on sensor readings and track conditions. Emergency actions always have the highest priority to avoid crashes.

## Open Challenge Algorithm

At the start of every run, we initialize all the sensors, calibrate the IMU, and wait for the start button. Once the run begins, the robot continuously reads wall distances, updates orientation data, and adjusts steering depending on the track conditions.

We also implemented adaptive speed control. In narrow sections, the robot slows down to improve stability and avoid collisions. In wider sections, it increases speed to complete laps more efficiently.

For lap counting, we use the MPU6050 gyroscope. Every detected 90° turn increases the accumulated yaw value until reaching the equivalent of three complete laps. Once that value is reached, the robot stops automatically.

This method allowed us to make the lap counting system work correctly in both clockwise and counterclockwise runs without needing separate logic for each direction.

## Vision Processing Strategy (ROIs)

We noticed that using the full camera image caused a lot of unstable detections. Reflections from the floor, random objects, and unnecessary data sometimes made the robot react too late or steer incorrectly.

To solve this, we divided the image into different Regions of Interest (ROIs), so the OpenMV only focuses on the most important parts of the frame.

### WS2812B RGB LED Matrix Module (4x4 / 16-bit)

To ensure reliable vision processing under varying ambient lighting conditions on the track, we integrated a 4x4 WS2812B RGB LED matrix module. Shadowing and uneven venue illumination previously affected color thresholding on the OpenMV H7 camera. By mounting this addressable LED matrix directly near the camera's field of view, we provide consistent, controlled lighting. This significantly improves the camera's ability to accurately detect and distinguish between red and green traffic pillars during the Obstacle Challenge.
## ROI	Purpose
Upper ROI	Detect pillars early and prepare the turn
Middle ROI	Main decision area for obstacle avoidance
Lower ROI	Ignore floor reflections and false detections

When multiple objects appear, we select the largest blob because it is usually the closest obstacle. We also added a small delay (~300 ms) to avoid repeated detections during turns.

This strategy made the robot much more stable and predictable during testing. Instead of improving the camera itself, we improved how the information was processed, which reduced false positives and gave us faster and smoother reactions.

## Parking Strategy

After finishing the 3 laps in the Obstacle Challenge, our robot performs a parallel parking maneuver inside the magenta parking zone. The system is still being refined, but our current strategy focuses more on reliability and consistency than speed.

To detect the parking area, we mainly use the HC-SR04 ultrasonic sensors. We look for a larger side gap and less obstruction in front of the robot. The OpenMV H7 can also help identify the parking area if visual references are available.

The maneuver is divided into three phases:

| Phase | Description |
|---|---|
| Alignment | Position the robot parallel to the parking zone |
| Entry | Turn smoothly into the parking space |
| Correction | Make small adjustments until centered |

During testing, we found several challenges:

- Limited parking space
- Ultrasonic noise at short distances
- Need for precise steering timing

To improve consistency, we reduced the parking speed and combined fixed steering sequences with sensor feedback. Right now, our goal is making the maneuver stable and repeatable instead of extremely fast.

Future updates will include better parking detection and more dynamic corrections before the final competition.

## Lateral Control Strategy

Instead of using a full PID controller, we decided to use a simpler threshold-based control system combined with IMU correction. This made the robot easier to tune and more stable on the Arduino Nano.

The robot constantly compares the left and right ultrasonic distances:

```cpp
error = distL - distR;

If the robot gets too close to one wall, we automatically correct the steering toward the opposite side to keep the robot centered.

To reduce sensor noise from the HC-SR04 sensors, we added exponential smoothing:

```cpp
suavizado = (suavizado * 0.7f) + (error * 0.3f);
```

For straight sections, the MPU6050 helps us correct small drifting errors using gyro feedback. This became especially important in the 1000 mm corridor, where long straight sections make drift more noticeable.

After many tests, we tuned the control constants to reduce oscillation while still keeping fast reactions near corners.

| Constant | Value |
|---|---|
| Kp | 2.5 |
| Ki | 0.01 |
| Kd | 1.2 |

We started with a low proportional gain and gradually increased it until the robot began oscillating. Then we reduced it slightly and added derivative damping to make the steering smoother and more stable.

# Power, Sensors and Software Architecture

## Power Architecture

The robot is powered by two 18650 batteries rated at 3.7 V each.

The batteries provide power to both the motors and the electronic systems of
the robot. The power system supplies the robot's control boards, sensors and
actuators.

### Battery Voltage Monitoring

A small digital voltmeter is connected to the robot to monitor the battery
voltage during testing.

During our tests, we observed that when the battery voltage reaches
approximately 7 V or below, the robot's movement becomes slower and its
performance changes.

Because of this, we monitor the battery voltage before and during testing to
help maintain consistent robot performance.

### Power System Failure and Iteration

On July 18, 2026, we experienced a power-related failure caused by connecting
the batteries in the wrong orientation. This caused one of the boards to burn.

After this incident, we became more careful when connecting the batteries and
checking their polarity before powering the robot.

This experience showed us the importance of verifying the power connections
before every test.

## Sensor Architecture

The robot uses ultrasonic sensors, an orientation sensor and a camera to
understand its environment and navigate the course.

### Ultrasonic Sensors

The ultrasonic sensors are distributed around the robot:

| Sensor | Position | Purpose |
|---|---|---|
| Sensor 1 | Front | Detect obstacles in front of the robot |
| Sensors 2–3 | Right side | Detect obstacles and distances on the right |
| Sensors 4–5 | Left side | Detect obstacles and distances on the left |

We selected these positions so that the robot could detect obstacles not only
on its sides but also in front of it.

The front sensor helps the robot detect obstacles before reaching them,
reducing the possibility of collisions.

The side sensors provide additional distance information during navigation and
help the robot understand the space around it.

### Sensor Testing and Reliability

Before testing the complete robot, we check that the ultrasonic sensors are
working correctly and providing valid readings.

The sensor programming has already been tested and adjusted, and all of the
ultrasonic sensors currently operate correctly.

During our testing, we have not experienced failures with the ultrasonic
sensors.

## BNO085

The BNO085 orientation sensor is used as a lap/turn counter.

The sensor provides orientation information that allows the robot to keep
track of its turns while navigating the course.

## OpenMV

The OpenMV camera is responsible for detecting the colors of the blocks.

The robot uses the detected block color to determine which direction it should
take:

| Detected Color | Direction |
|---|---|
| Green | Left |
| Red | Right |

This allows the robot to determine the appropriate direction when approaching
an obstacle.

# Software Architecture

The robot combines information from several electronic systems to control its
movement and navigate the course.

### Main Systems

- **OpenMV:** Detects the color of the blocks.
- **HC-SR04:** Measures distances around the robot.
- **BNO085:** Provides orientation information used to count turns/laps.
- **PID control:** Controls and corrects the robot's movement.

## PID Control

The robot uses PID control as part of its movement control system.

PID continuously adjusts the robot's movement according to the difference
between the desired movement and the current behavior of the robot.

This allows the robot to make corrections while moving instead of relying only
on fixed movement commands.

# Obstacle Strategy

Obstacle detection combines the information obtained from the OpenMV camera
and the ultrasonic sensors.

The OpenMV identifies the color of the obstacle, while the ultrasonic sensors
provide distance information around the robot.

When a colored block is detected:

1. The OpenMV identifies the block color.
2. The robot determines the required direction.
3. A green block results in a left direction.
4. A red block results in a right direction.
5. The ultrasonic sensors provide distance information to help prevent
   collisions.

This combination allows the robot to use both visual and distance information
during obstacle navigation.

# Testing and Iteration

Testing has been an important part of the development process.

During testing, we identified several aspects that could affect the robot's
performance:

- Battery voltage affects the robot's movement speed.
- Incorrect battery orientation can damage the electronics.
- Sensor placement is important for detecting obstacles around the robot.
- Sensor operation is checked before testing.
- The OpenMV color detection determines the direction used for obstacle
  navigation.
- PID control is used to continuously correct the robot's movement.

The current sensor configuration was maintained because the ultrasonic sensors
have operated correctly during our tests and provide coverage of the front,
left and right sides of the robot.

# Engineering Decisions

Our design decisions were based on the behavior observed during testing.

### Sensor Placement

We distributed the ultrasonic sensors across the front and both sides of the
robot instead of concentrating them in a single area.

The reason was to give the robot information about obstacles in multiple
directions and reduce the possibility of reaching the blocks without detecting
them.

### Battery Monitoring

We added a digital voltmeter to monitor the battery voltage because testing
showed that lower battery voltage affects the robot's movement.

This gives us a direct way to check the battery condition during testing.

### Color-Based Direction

We use the OpenMV camera to distinguish between red and green blocks.

The color determines the direction:

- Green → Left
- Red → Right

This provides the robot with a visual decision-making system for obstacle
navigation.

### Power Connection Safety

After the board failure on July 18, 2026 caused by reversing the battery
orientation, checking battery polarity became an important part of our testing
procedure.

# System Interaction

The robot's subsystems work together during navigation.

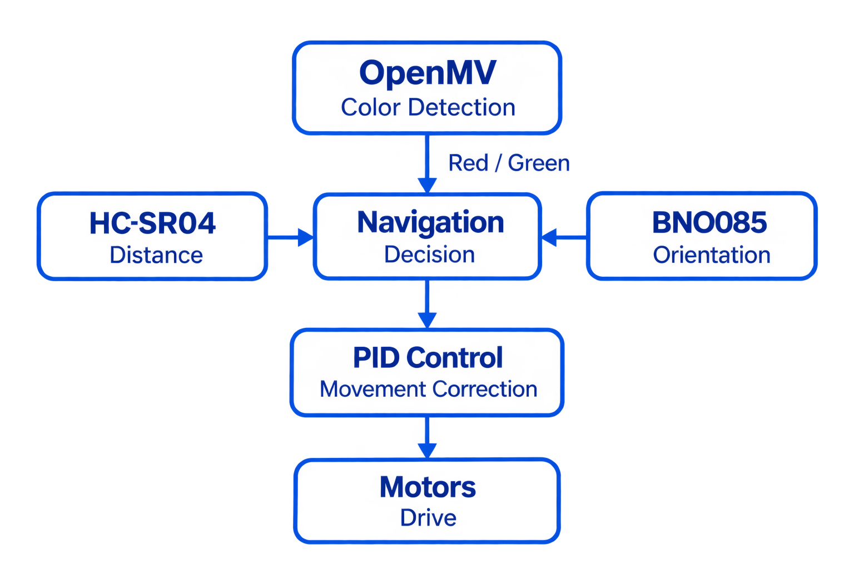
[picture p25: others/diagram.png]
System Interaction Diagram


The OpenMV camera detects the color of the obstacle and provides red or green
information to the navigation system.

The HC-SR04 ultrasonic sensors provide distance information, while the BNO085
provides orientation information used to count turns/laps.

The navigation system uses this information to determine the appropriate
movement. PID control is then used to correct the robot's movement before the
commands are sent to the motors.

# Testing Workflow

Before each complete robot test, we check the operation of the sensors and
verify the battery connection.

The general testing process is:

1. Check the battery polarity.
2. Check the battery voltage.
3. Verify that the ultrasonic sensors are operating correctly.
4. Verify the OpenMV color detection.
5. Check the BNO085 orientation information.
6. Run the robot.
7. Observe its movement and navigation.
8. Identify problems or changes in performance.
9. Adjust the system when necessary.
10. Repeat the test.

This iterative process has helped us identify problems related to power,
sensor operation and robot movement.

# Testing & Tuning

| Test | Result | Adjustment |
|---|---|---|
| Open Challenge (wide corridor) | 18/20 successful runs | — |
| Open Challenge (narrow corridor) | 14/20 successful runs | Reduced speed to PWM 110 |
| Obstacle avoidance | 17/20 correct detections | Increased detection timeout |
| IMU lap counting | 20/20 correct | — |
| Startup alignment | 19/20 centered correctly | Improved alignment gain |

Most of our tuning focused on making the robot more stable under different corridor sizes and lighting conditions.

## Problems & Iterations

During the development of our robot, we faced several problems related to mechanics, electronics, and software.  
Instead of ignoring them, we used each issue as an opportunity to improve the robot and better understand how every part of the system behaves in real conditions.

| Problem | Impact | Solution |
|---|---|---|
| Excessive dimensions in the original LEGO chassis | The robot struggled in tight curves and narrow sections | We redesigned the structure and moved to a more compact and lightweight 3D-printed chassis |
| Signal instability in sensors | We noticed inconsistent wall detection and unstable trajectory corrections | We created a custom PCB and improved the soldering quality to reduce electrical noise and improve reliability |
| Limitations in simultaneous color detection | Sometimes the robot reacted incorrectly to obstacles | We optimized the OpenMV firmware and improved the AI processing logic for more stable detections |
| Insufficient internal space for components | Organizing the electronics and wiring became difficult inside the chassis | We slightly increased the chassis length to create more internal space and improve cable management |

# Evolution From 2025 to 2026

Our 2026 robot is not just a small upgrade from the 2025 version. We rebuilt almost the entire system based on everything we learned during the international competition.

| System | 2025 | 2026 Final |
|---|---|---|
| Chassis | LEGO Technic | Custom 3D-printed PLA |
| Vision | OpenMV H7 | OpenMV H7 |
| Controller | EV3 Brick | Arduino Nano |
| Steering | EV3 motor | Steren MOT-110 servo |
| Weight | ~1.2 kg | ~0.7 kg |

One of the biggest changes happened mid-season when we replaced the HuskyLens with the OpenMV H7 again. During testing, the HuskyLens was not sending enough continuous data, causing the steering servo to oscillate. Switching back to OpenMV solved the issue and gave us much smoother and more stable control.

## Vehicle Evolution — Before & After

| View | Before | After |
|:---:|:---:|:---:|
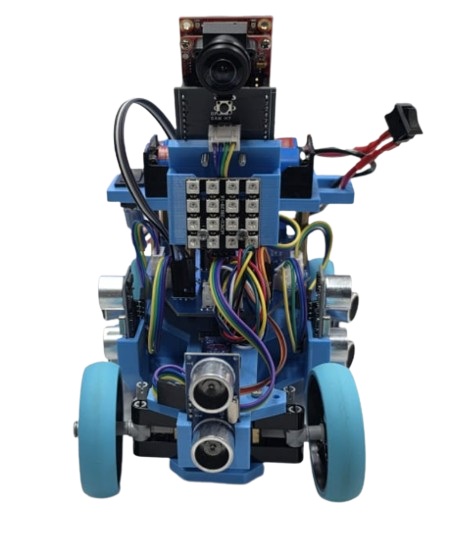
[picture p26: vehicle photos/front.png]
| **Front** |  |  |
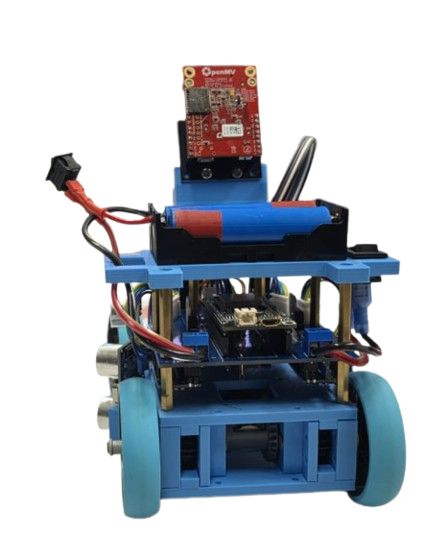
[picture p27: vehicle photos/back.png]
| **Back** |  |  |
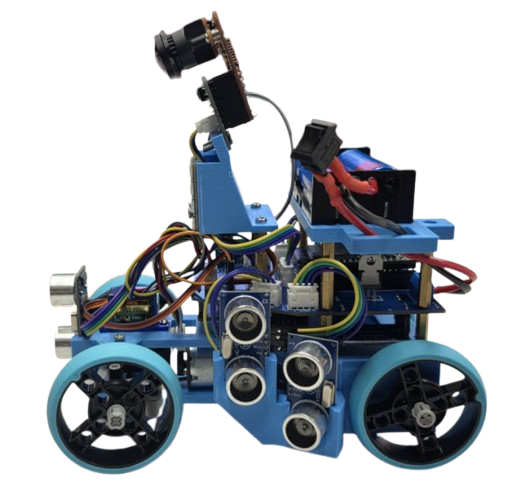
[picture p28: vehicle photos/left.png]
| **Left** |  |  |
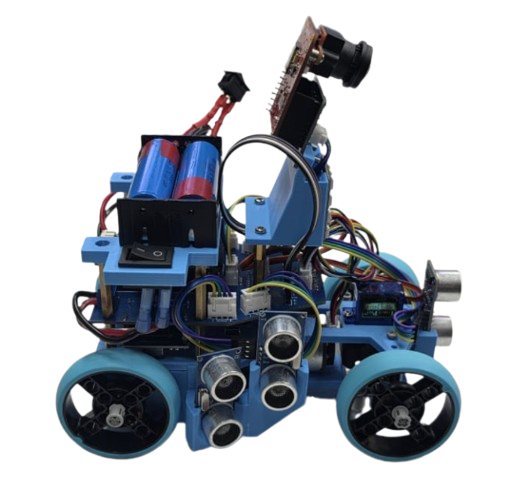
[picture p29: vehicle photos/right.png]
| **Right** |  |  |
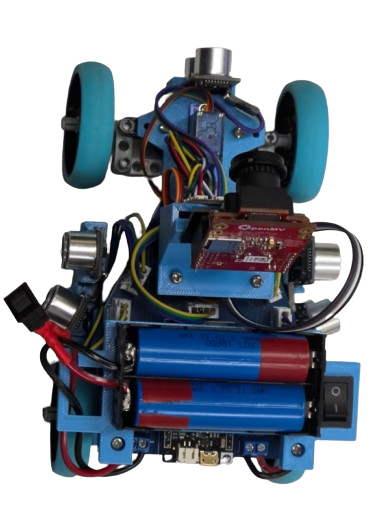
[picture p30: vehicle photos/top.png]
| **Top** |  |  |
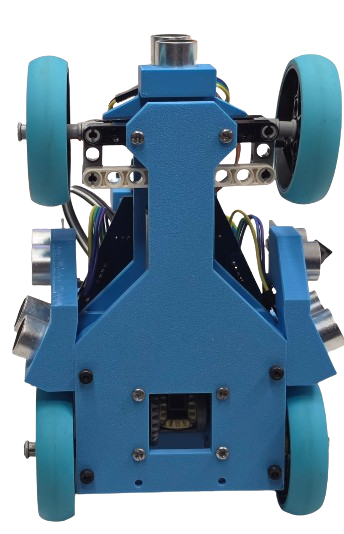
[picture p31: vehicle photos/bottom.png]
| **Bottom** |  |  |

# Engineering Decisions & Trade-offs

Throughout development, we constantly balanced simplicity, reliability, and performance.

| Decision | Why we chose it |
|---|---|
| Arduino Nano instead of Raspberry Pi | Easier to debug and understand as a team |
| OpenMV instead of HuskyLens | More stable continuous data stream |
| Short wheelbase | Better turning radius in tight corridors |
| Threshold-based control | More predictable than a complex PID setup |

We focused on building a system that every team member could fully understand and maintain instead of relying on overly complex solutions.

# Risk Analysis

| Risk | Mitigation |
|---|---|
| IMU drift | Accumulated yaw tracking |
| Wrong color detection | Largest blob selection + timeout |
| Battery voltage drop | Voltmeter checks before runs |
| Wall collisions | Adaptive speed reduction |
| Servo drift | IMU correction on straight sections |

We also documented and solved several hardware problems during development, including PCB solder bridges and drivetrain binding after reprinting the chassis.

## Wiring Diagram

<p align="center">
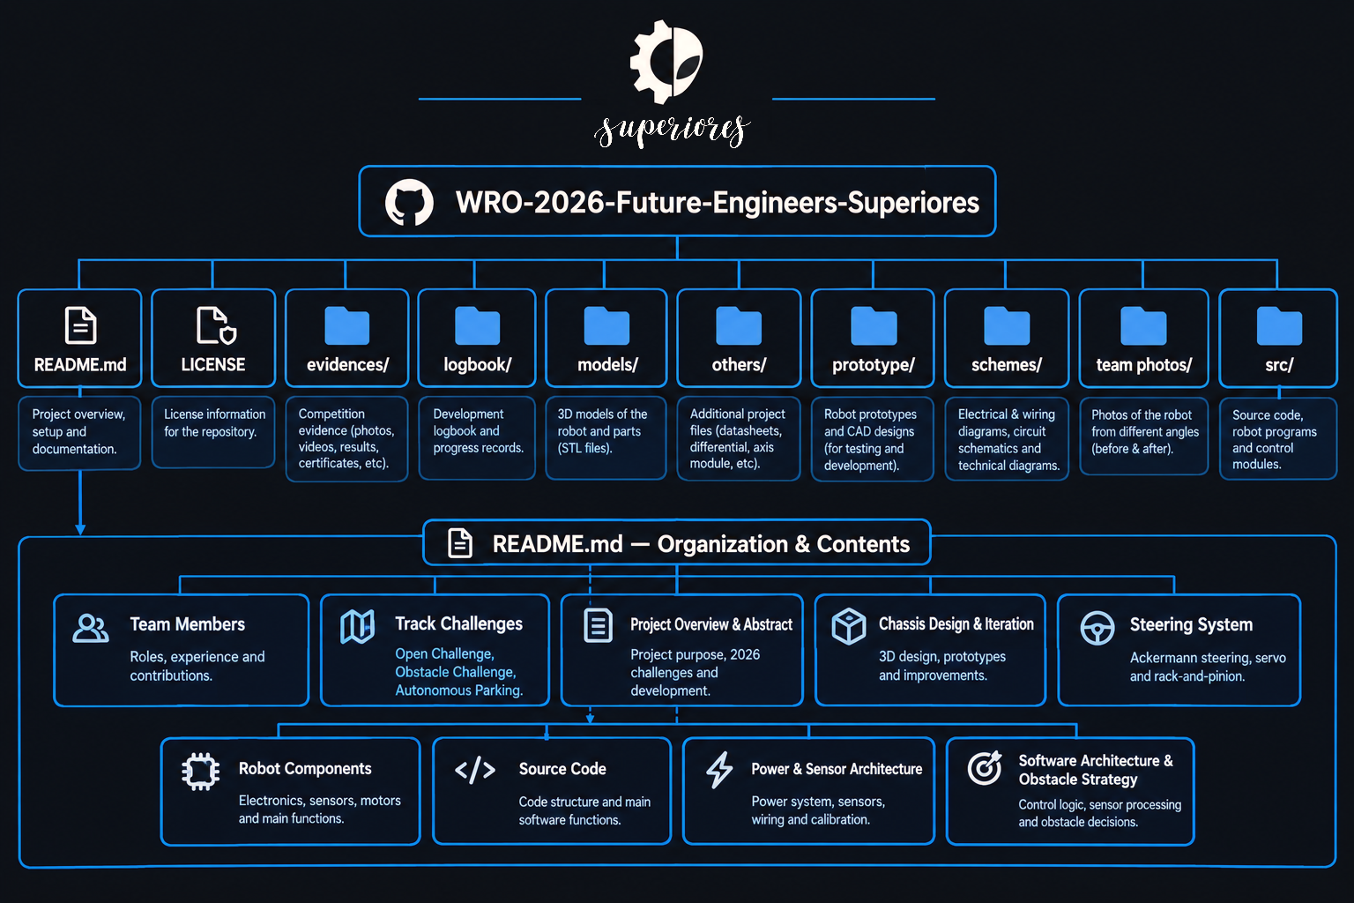
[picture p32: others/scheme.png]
Robot Wiring Diagram
  
</p>

The repository includes the full Arduino code, wiring diagrams, PCB schematics, STL files, and robot photos so the entire project can be reproduced and improved in the future.

# Components & Cost

| Component | Qty |
|---|-----|
| OpenMV H7 | 1 |
| Arduino Nano | 1 |
| HC-SR04 | 3 |
| MPU6050 | 1 |
| TB6612FNG | 1 |
| Steren MOT-110 Servo | 1 |
| Li-ion Batteries | 2 |

**Estimated total cost: approximately 154 USD**

# In conclusion (●'◡'●)

This repository documents the complete development process of our WRO 2026 Future Engineers robot, from the first design concepts to the latest competition-ready version.

Throughout the season, we redesigned almost every part of the system based on testing, failures, and continuous improvements. The project includes a fully custom 3D-printed chassis, Arduino Nano control system, OpenMV H7 vision processing, ultrasonic navigation, IMU-based lap tracking, and obstacle avoidance strategies developed specifically for the 2026 rules.

Instead of focusing only on final results, this repository also documents the engineering decisions behind the robot, including hardware changes, software iterations, PCB problems, steering improvements, sensor calibration, and real testing data collected during development.

Our goal was to build a robot that is not only competitive, but also understandable, reliable, and fully developed by our team through experimentation and iteration.

This repository contains:
- Full Arduino source code
- Wiring diagrams and PCB schematics
- 3D models and printable STL files
- Robot photos and assembly references
- Engineering documentation and testing results
- Development history and design decisions

We hope this project can also help future teams learn more about robotics, engineering design, and autonomous vehicle development.

<div align="center">

# THANK YOU FOR READING (´▽｀)

### Thank you for taking the time to explore our project and follow our development process throughout the WRO 2026 season.

### We truly appreciate your time, interest, and support.

<br>

**Team Superiores**  
*WRO Future Engineers 2026*

</div>

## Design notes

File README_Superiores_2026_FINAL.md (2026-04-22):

# 🤖 WRO-2026-Future-Engineers — Los Grises Superiores

Official repository of **Team Los Grises Superiores** for the **Future Engineers – World Robot Olympiad 2026**.

> **Season theme:** Autonomous Self-Driving Cars — Open Championship Online  
> **Category:** Future Engineers | **Age group:** 14–22

<div align="center">
team-banner
</div>

---

## 📸 Team Photo

<div align="center">
  team-photo
</div>

---

## 👥 Team Members

### 🧑‍🏫 Eduardo Alvarado González — Coach & Founder

<div align="center">
Eduardo Gonzalez
</div>

An engineer and professor who founded **Los Grises Superiores** in 2014. Under his leadership, the team has achieved outstanding results at national and international level in WRO and the Mexican Robotics Tournament (TMR).

---

### 💻 Christopher Pérez Cortés — Programming & Electronics
**Age:** 14

<div align="center">
  Christopher Pérez photo
</div>

Christopher joined the **Robotics Club** at *Escuela Normal Superior "Profr. Moisés Sáenz Garza"* earlier this year after completing an intensive robotics course. Currently in his third year of middle school, he has quickly developed skills in **electronics, programming (Arduino C++), and 3D modeling (Onshape)**. WRO 2026 is his first international competition.

---

### 🔧 Bárbara Daiana García Balboa — Design & Assembly
**Age:** 13

<div align="center">
  Bárbara Daiana photo
</div>

Bárbara joined the robotics club two months ago after completing two intensive robotics courses. She is responsible for **mechanical design, chassis assembly, and structural testing**. WRO 2026 is her first competition.

---

### 🛠️ Paulina Ibarra Martínez — Design & Construction
**Age:** 21

<div align="center">
  Paulina Martinez photo
</div>

Paulina brings extensive competition experience to the team. She has participated in **two Mexican Robotics Tournaments** (5th place) and served as junior coach in WRO 2024 (3rd place) and TMR 2025 (1st place nationally). Her role this season focuses on **structural design, component integration, and mentoring the younger members**.

---

## 📚 Table of Contents

- [Project Overview & Abstract](#project-overview--abstract)
- [Vehicle Photos](#vehicle-photos)
- [Project Videos](#-project-videos)
- [Criterion 1 — Mobility & Mechanical Design](#criterion-1--mobility--mechanical-design)
  - [Chassis Design & Iteration](#chassis-design--iteration)
  - [Steering System](#steering-system)
  - [Traction System](#traction-system)
  - [Mechanical Trade-offs & Decisions](#mechanical-trade-offs--decisions)
- [Criterion 2 — Power & Sensor Architecture](#criterion-2--power--sensor-architecture)
  - [Power System & Budget](#power-system--budget)
  - [Wiring Diagram](#wiring-diagram)
  - [Sensor Selection & Placement](#sensor-selection--placement)
  - [Calibration Methods](#calibration-methods)
- [Criterion 3 — Software Architecture & Obstacle Strategy](#criterion-3--software-architecture--obstacle-strategy)
  - [System Overview](#system-overview)
  - [State Machine](#state-machine)
  - [Open Challenge Algorithm](#open-challenge-algorithm)
  - [Obstacle Challenge Algorithm](#obstacle-challenge-algorithm)
  - [PID Control Implementation](#pid-control-implementation)
  - [Testing & Tuning Process](#testing--tuning-process)
- [Criterion 4 — Systemic Thinking & Engineering Decisions](#criterion-4--systemic-thinking--engineering-decisions)
  - [Evolution from 2025 to 2026](#evolution-from-2025-to-2026)
  - [Constraints & Trade-offs](#constraints--trade-offs)
  - [Risk Analysis & Mitigation](#risk-analysis--mitigation)
- [Criterion 5 — Repository & Reproducibility](#criterion-5--repository--reproducibility)
  - [How to Build & Run](#how-to-build--run)
  - [Components & Bill of Materials](#components--bill-of-materials)
- [References](#references)

---

## Project Overview & Abstract

We present the **development and implementation of an autonomous vehicle** designed for the **World Robot Olympiad 2026 – Future Engineers** category. This robot is the direct evolution of our 2025 competition vehicle, rebuilt from the ground up with a **3D-printed chassis**, a new **HuskyLens AI camera**, and a refined **Arduino-based control architecture**.

The **Future Engineers** category requires a self-driving car to complete two challenges:

1. **Open Challenge** — Complete **3 laps** autonomously. Starting position, direction (CW/CCW), and inner wall distance (600 mm or 1000 mm) are randomized each run.
2. **Obstacle Challenge** — Complete **3 laps** reacting to colored traffic pillars (red → pass right, green → pass left), then perform a **parallel parking maneuver** in a magenta-delimited bay (width: 20 cm, length: 1.5× robot length).

**Key 2026 changes we addressed in our design:**
- Variable inner corridor width (600 mm or 1000 mm) — requires adaptive speed and steering
- Parking points only awarded if at least one full lap is completed
- New documentation rubric with 5 engineering criteria (30 points total)

Documentation (this repository) accounts for **~25% of the total score (30/122 points)**.

---

## Vehicle Photos

<div align="center">

| Front | Back |
|:--:|:--:|
|  |  |

| Top | Bottom |
|:--:|:--:|
|  |  |

| Left | Right |
|:--:|:--:|
|  |  |

</div>

> 📁 Full-resolution photos available in the [`v-photos/`](./v-photos/) folder.

---

## 🎥 Project Videos

<div align="center">

### 🧩 Open Challenge


### 🚧 Obstacle Challenge


</div>

> Each video shows the vehicle operating autonomously for at least 30 seconds, as required by the WRO 2026 rules (Section 7).

---

---

## Criterion 1 — Mobility & Mechanical Design

### Chassis Design & Iteration

The 2025 robot used a **LEGO Mindstorms EV3** chassis — modular and quick to assemble but heavy (~1.2 kg with electronics), limited in geometry flexibility, and constrained by the EV3 brick's processing power for real-time vision.

For 2026 we migrated to a **fully custom 3D-printed chassis** designed in **Onshape**. The key design requirements were:

| Requirement | Rationale |
|---|---|
| Max dimensions: 300 × 200 × 300 mm | WRO rule 9.17 |
| Max weight: 1.5 kg | WRO rule 11.2 |
| Ackermann-style front steering | Rules prohibit differential drive (11.3, 11.5) |
| Rear-wheel drive via DC motor | Single drive motor simplifies wiring and control |
| Open front bay for ultrasonic sensors | Field-of-view requirement for wall detection |

**Iteration history:**
- **Version 1 (February 2026):** Initial flat-plate chassis. Problem: insufficient rigidity when servo torque was applied; steering linkage deflected under load.
- **Version 2 (March 2026):** Added triangular gussets at servo mount and increased wall thickness from 2 mm to 3 mm. Weight increased by ~40 g but deflection was eliminated.
- **Version 3 (April 2026, current):** Reduced overall length by 18 mm to improve cornering clearance in the narrow 600 mm corridor; relocated the Arduino Nano to a lower center of gravity position.

<div align="center">
Chassis CAD

*Fig. 1 — Onshape CAD render of Version 3 chassis*
</div>

All chassis STL files are available in the [`models/`](./models/) directory.

---

### Steering System

The front axle uses an **Ackermann steering geometry** implemented through a servo-actuated rack-and-pinion linkage built from LEGO Technic rack pieces (part 64781) integrated into the 3D-printed front module.

| Parameter | Value |
|---|---|
| Steering servo | SG90 (9g, 1.8 kg·cm stall torque) |
| Steering range | ~30° left / 30° right from center |
| Center pulse width | 1500 µs |
| Left limit | 1100 µs (`IZQUIERDA = 45`) |
| Right limit | 1900 µs (`DERECHA = 135`) |
| Control resolution | 1° (Arduino `Servo.write()`) |

**Why Ackermann?** The inner and outer front wheels trace different radius arcs in a turn. Without Ackermann compensation, the inner wheel scrubs, reducing precision and increasing wear. Our linkage approximates this geometry within the packaging constraints.

**Trade-off considered:** A full Ackermann trapezoid would require a wider front axle, exceeding the 200 mm width limit. We used a simplified tie-rod geometry that achieves approximately 70% Ackermann correction — sufficient for the track radii encountered in WRO (minimum ~300 mm inner radius).

---

### Traction System

| Parameter | Value |
|---|---|
| Drive motor | DC motor with gearbox (included in RC chassis base) |
| Driver IC | TB6612FNG dual H-bridge |
| Drive wheels | Rear axle, both wheels connected via gear train (not independent) |
| Gear ratio | Approx. 1:30 (estimated from encoder counts vs. measured distance) |

**Speed range tested:**

| PWM value | Measured speed | Use case |
|---|---|---|
| 110 | ~0.28 m/s | Narrow corridor / front obstacle |
| 130 | ~0.36 m/s | Normal straight section |
| 150 | ~0.44 m/s | Wide open corridor |

We tested 1:20 and 1:50 gear options. At 1:20 the robot was too fast to react to pillars within the sensor latency budget. At 1:50 acceleration was too slow to complete 3 laps within the 3-minute time limit. We chose 1:30 as the best trade-off between speed and control responsiveness.

> ⚠️ WRO rule 11.5 prohibits electronic differential (one motor per side). Our rear axle connects both wheels to a single motor through the gear train, fully compliant.

---

### Mechanical Trade-offs & Decisions

| Decision | Option A (chosen) | Option B (rejected) | Reason |
|---|---|---|---|
| Chassis material | 3D-printed PLA | LEGO Technic | Custom geometry, lower weight |
| Steering | Servo + rack | Differential steering | Rules require ackermann-type steering |
| Drive | Single DC motor | Two motors (coupled) | Simpler, lighter, compliant with 11.5 |
| Camera position | Front-center, tilted 20° down | Side-mounted | Better field of view for pillar detection and wall proximity |

---

## Criterion 2 — Power & Sensor Architecture

### Power System & Budget

The robot uses **two separate power rails** to isolate motor noise from the control electronics:

| Rail | Source | Consumers | Estimated current |
|---|---|---|---|
| 5 V logic | 7.4 V LiPo → Mini 560 step-down (5 V / 3 A) | Arduino Nano, MPU6050, HuskyLens, HC-SR04 ×3 | ~800 mA peak |
| Motor rail | 7.4 V LiPo (direct) | TB6612FNG + DC motor | ~1.5 A peak |

**Power budget analysis:**

| Component | Typical current (mA) |
|---|---|
| Arduino Nano | 20 |
| MPU6050 | 3.9 |
| HuskyLens | 320 (active AI) |
| HC-SR04 ×3 | 45 (15 mA each) |
| SG90 servo (active) | 250 |
| **Total logic rail** | **~640 mA** |
| DC motor (avg.) | 800–1500 |
| **Total motor rail** | **~1500 mA** |

The Mini 560 step-down is rated at 3 A continuous; our logic rail draws ~640 mA, giving a **safety margin of ~4.7×**. This margin accounts for HuskyLens inference spikes and servo stall.

**Failure mode considered:** If the LiPo voltage drops below ~6.5 V, the Mini 560 drops out of regulation. We added a **mini digital voltmeter** visible on the chassis to monitor battery state before each run.

---

### Wiring Diagram

> 📁 Full wiring schematic (PDF and PNG) available in [`schemes/`](./schemes/).

**Connection summary:**

```
LiPo (7.4 V)
    ├── Mini 560 Step-Down → 5 V rail
    │       ├── Arduino Nano (5 V pin)
    │       ├── MPU6050 (I2C: SDA→A4, SCL→A5)
    │       ├── HuskyLens (I2C: SDA→A4, SCL→A5)
    │       └── HC-SR04 ×3
    │               Front  TRIG→D7  ECHO→D6
    │               Left   TRIG→D3  ECHO→D2
    │               Right  TRIG→D5  ECHO→D4
    └── TB6612FNG (VMOT = 7.4 V)
            ├── DC Motor (rear axle)
            │       AIN1→D10  AIN2→D11  PWMA→D9
            └── SG90 Servo (signal→D8)
```

**I2C bus:** Both the MPU6050 and HuskyLens share the I2C bus (address 0x60 for HuskyLens, 0x68 for MPU6050). No address conflict exists.

---

### Sensor Selection & Placement

#### HC-SR04 Ultrasonic Sensors (×3)

| Sensor | Position | Purpose |
|---|---|---|
| Front | Center front, horizontal | Detect wall / corner ahead |
| Left | Left side, horizontal | Measure distance to inner/outer wall |
| Right | Right side, horizontal | Measure distance to inner/outer wall |

**Why ultrasonic over IR?** The WRO field uses matte black walls. IR reflectance sensors give unreliable readings on dark surfaces; ultrasonic sensors are color-independent.

**Placement rationale:** Sensors are mounted at wheel axle height (~50 mm from ground) to avoid sensing the floor in curved sections where the robot tilts slightly.

**Known limitation:** HC-SR04 has a minimum sensing distance of ~2 cm and a cone angle of ~15°. At high speeds, multiple echo returns can cause occasional spikes. We implemented a moving-average filter in software (see Criterion 3).

#### MPU6050 IMU (6-DOF)

Used exclusively for **yaw (rotation) tracking**. The gyroscope integrates angular velocity to give heading. We use accumulated yaw to:
1. Count 90° turns (each corner = 1 turn, 4 turns = 1 lap)
2. Detect and correct drift in straight sections
3. Determine lap count (3 laps = 1080° accumulated yaw)

**Calibration:** On startup, `mpu.calcOffsets(true, true)` is called with the robot stationary for ~3 seconds to compute gyro bias. The robot must not be moved during this window — indicated by the serial monitor message `"Calibrando IMU... No mover el robot."`.

#### HuskyLens AI Camera (SEN0305)

| Parameter | Value |
|---|---|
| Resolution | 320 × 240 px |
| Interface | I2C (up to 400 kHz) |
| Mode used | Color Recognition |
| Trained objects | ID 1 = Red pillar, ID 2 = Green pillar |
| Frame rate | ~30 FPS (hardware AI, no host processing) |
| Mounting | Front-center, tilted 20° downward |

**Why HuskyLens instead of OpenMV (2025)?** The OpenMV H7 Plus required Python scripting and UART communication with EV3, introducing ~50 ms latency per frame. HuskyLens runs inference on-chip and returns block coordinates via I2C in <10 ms. This 5× latency reduction is critical at our operating speeds.

**Trade-off:** HuskyLens requires manual training on the physical pillars under competition lighting. We performed 3 training sessions (lab, outdoor, gym) and selected the model with the best generalization. The camera angle of 20° was chosen empirically: 0° caused false detections of the floor line; 30° reduced detection range to <40 cm.

---

### Calibration Methods

| Sensor | Calibration method | When |
|---|---|---|
| MPU6050 | Static bias computation (`calcOffsets`) | At power-on, before start button |
| HuskyLens | On-device training with 20 samples per color | Before competition, stored in camera flash |
| HC-SR04 | Measured against known distances (10, 20, 50 cm ruler) | Manual verification; no runtime calibration needed |
| Servo center | Adjusted `CENTRO` constant to achieve mechanically straight driving | One-time setup per robot rebuild |

---

## Criterion 3 — Software Architecture & Obstacle Strategy

### System Overview

The entire control system runs on a **single Arduino Nano (ATmega328P, 16 MHz)**. There is no separate SBC; all sensor reading, decision logic, and motor control happen in the same `loop()` cycle, which executes in approximately **25 ms** (40 Hz update rate).

**Software modules:**

| Module | Functions | Description |
|---|---|---|
| `IMU` | `actualizarIMU()`, `actualizarConteoGiros()`, `giroRelativo()` | Reads MPU6050, integrates yaw, counts 90° turns |
| `Ultrasonics` | `medirDistancia(TRIG, ECHO)` | Returns distance in cm via HC-SR04 pulse timing |
| `PID` | Inline in `loop()` | Lateral wall-following with gyro correction |
| `HuskyLens` | `huskylens.request()`, `huskylens.read()` | Queries camera for color block detections |
| `Drive` | `avanzar(speed)`, `detener()`, `girarSuave()` | Controls TB6612FNG and SG90 servo |
| `Start Sequence` | `faseInicio` state machine | 3-phase startup alignment |

---

### State Machine

```
┌─────────────────────────────────────────────────────────────────┐
│                      SYSTEM STATES                              │
├──────────────┬──────────────────────────────────────────────────┤
│ INICIO       │ 3-phase startup alignment (wall centering)       │
│   Phase 0    │   Front wall detected → escape turn              │
│   Phase 1    │   Anti-corner S-maneuver                         │
│   Phase 2    │   Fine centering with ultrasonics                │
├──────────────┼──────────────────────────────────────────────────┤
│ LANE_FOLLOW  │ PID lateral + IMU gyro correction                │
│              │ Adaptive speed (110/130/150 PWM)                 │
├──────────────┼──────────────────────────────────────────────────┤
│ AVOID_COLOR  │ HuskyLens detects pillar →                       │
│              │   ID1 (red)  → steer RIGHT (DERECHA)             │
│              │   ID2 (green)→ steer LEFT (IZQUIERDA)            │
│              │ Returns to LANE_FOLLOW after 300 ms              │
├──────────────┼──────────────────────────────────────────────────┤
│ EMERGENCY    │ distL < 7 cm  → hard right                       │
│              │ distR < 7 cm  → hard left                        │
│              │ distF < 15 cm → turn toward open side            │
├──────────────┼──────────────────────────────────────────────────┤
│ STOP         │ yawAcumulado ≥ 1080° → detener() + while(1)      │
└──────────────┴──────────────────────────────────────────────────┘
```

**State transitions are priority-ordered:** STOP > EMERGENCY > AVOID_COLOR > LANE_FOLLOW > INICIO.

---

### Open Challenge Algorithm

```
SETUP:
  Initialize I2C (MPU6050 + HuskyLens)
  Calibrate IMU (calcOffsets)
  Reset yawAcumulado = 0, girosContados = 0
  Wait for Start button

LOOP (every 25 ms):
  1. actualizarIMU()          ← integrate gyro, detect 90° threshold
  2. actualizarConteoGiros()  ← increment girosContados, accumulate yaw
  3. IF yawAcumulado >= 1080° → STOP (3 laps done)
  4. Read distF, distL, distR from HC-SR04
  5. IF inicio: run 3-phase alignment, RETURN
  6. Compute pasilloEstrecho (distL<15 AND distR<15)
  7. Set velocidad: distF<18→110, distF<30→130, else→150
  8. Compute PID (distL - distR error, with exponential smoothing)
  9. Apply IMU correction (giroRelativo() on straight sections)
  10. Check EMERGENCY overrides
  11. Check HuskyLens color detection (NOT in emergency)
  12. girarSuave() + avanzar(velocidad)
```

**Lap counting method:** The MPU6050 accumulates yaw. Each 90° crossing (with a hysteresis threshold of ±5°) increments `girosContados`. After 12 increments (3 laps × 4 corners), `yawAcumulado` reaches 1080° and the robot stops. This method is **direction-agnostic** — it works for both CW and CCW because the magnitude of yaw is accumulated, not the sign.

---

### Obstacle Challenge Algorithm

The obstacle challenge extends the open challenge with:

1. **Color detection:** HuskyLens in Color Recognition mode. When a block is detected, the largest block by area is selected (multi-block priority logic).
2. **Avoidance maneuver:** Steer toward the correct side, hold for 300 ms (`tiempoColor`), then return to lane-follow. The 300 ms was determined empirically across 20 test runs to give consistent clearance without overshooting.
3. **Parking (Obstacle Challenge only):** After 3 laps, the robot must locate and park in the magenta bay. *(Parking implementation in progress — will be committed before competition deadline.)*

**Edge case handled:** If both left and right distances are < 15 cm (narrow corridor), `evitandoColor` is suppressed to avoid steering conflicts between the wall-following PID and the color avoidance.

---

### PID Control Implementation

The lateral wall-following PID uses the **difference between left and right ultrasonic distances** as the error signal:

```
error = distL - distR
```

A positive error (robot closer to right wall) produces a positive PID output, steering left to re-center.

**Exponential smoothing (low-pass filter):**
```cpp
suavizado = (suavizado * 0.7f) + (error * 0.3f);
error     = suavizado;
```
This reduces HC-SR04 noise spikes from affecting the steering output.

**IMU gyro correction (straight sections only):**
```cpp
if (!enGiro) {
  float giro = giroRelativo();        // yaw deviation from last reference
  if (abs(giro) > UMBRAL_GIRO_CURVA) {
    salidaPID -= giro * 0.8f;         // proportional correction
    if (abs(giro) > UMBRAL_GIRO_EMERGENCIA) {
      salidaPID = (giro > 0) ? -(DERECHA-CENTRO) : (DERECHA-CENTRO); // max correction
    }
  }
}
```
The gyro correction prevents the robot from drifting sideways during long straight sections, which is especially important in the 1000 mm wide corridor variant.

**Tuned PID constants:**

| Constant | Value | Effect |
|---|---|---|
| `Kp` | 2.5 | Proportional gain — main correction strength |
| `Ki` | 0.01 | Integral — eliminates steady-state offset |
| `Kd` | 1.2 | Derivative — damps oscillation near center |

**Tuning process:** We started with Kp=1.0, Ki=0, Kd=0 and increased Kp until oscillation appeared (~3.5), then backed off to 2.5. Kd was added to dampen oscillation. Ki was added at 0.01 to compensate for the systematic error caused by slight servo center offset.

---

### Testing & Tuning Process

| Test | Metric | Result | Action taken |
|---|---|---|---|
| 3-lap consistency (open, wide) | Completion rate | 18/20 runs | — |
| 3-lap consistency (open, narrow) | Completion rate | 14/20 runs | Reduced speed in narrow mode to 110 |
| Pillar avoidance (obstacle) | Correct side rate | 17/20 pillars | Adjusted `tiempoColor` from 200→300 ms |
| IMU drift over 3 laps | Lap count accuracy | 100% (20/20) | — |
| Startup alignment | Centered within 3 cm | 19/20 runs | Improved Phase 2 proportional gain |

---

## Criterion 4 — Systemic Thinking & Engineering Decisions

### Evolution from 2025 to 2026

The 2025 robot was a strong performer (international competition participant), but the 2025 architecture had fundamental constraints that motivated a full rebuild:

| Aspect | 2025 (EV3 + OpenMV) | 2026 (Arduino + HuskyLens) | Why changed |
|---|---|---|---|
| Chassis | LEGO Technic | 3D-printed PLA | Weight reduction, custom geometry |
| Vision | OpenMV H7 Plus (Python, UART) | HuskyLens (on-device AI, I2C) | 5× lower latency, no host CPU cost |
| Controller | EV3 Intelligent Brick | Arduino Nano + TB6612FNG | Faster loop rate, direct PWM control |
| IMU | DFRobot BNO055 | MPU6050 | Lower cost, simpler library, sufficient precision |
| Weight | ~1.2 kg | ~0.7 kg (estimated) | Better power-to-weight, faster acceleration |

This is not a minor update — it is a **complete system redesign** inspired by the 2025 experience, executed by a largely new team with guidance from veteran members.

---

### Constraints & Trade-offs

**Constraint 1 — Processing power:** The Arduino Nano (ATmega328P) has only 2 KB SRAM and runs at 16 MHz. This ruled out onboard image processing. We offloaded vision entirely to HuskyLens.

**Constraint 2 — Dimensional limits:** 300 × 200 mm footprint constrains the wheelbase and track width. We optimized for a short wheelbase (better turning radius) at the cost of slightly reduced straight-line stability.

**Constraint 3 — Time (team readiness):** Two of three team members are competing in their first WRO. We chose a simpler hardware stack (Arduino vs. Raspberry Pi) so members could understand and debug the entire system independently.

**Constraint 4 — 2026 rule change — narrow corridor:** The inner walls can now be 600 mm apart (vs. always 1000 mm in 2025). Our adaptive speed logic directly addresses this: `pasilloEstrecho` reduces speed when both side distances are < 15 cm.

**Trade-off: HuskyLens vs. custom OpenCV pipeline**
- HuskyLens pros: plug-and-play, on-chip, 10 ms latency, no calibration complexity
- HuskyLens cons: fixed detection classes (trained manually), less flexible than scripted vision
- Decision: HuskyLens. Reliability and latency outweigh flexibility for this challenge.

---

### Risk Analysis & Mitigation

| Risk | Probability | Impact | Mitigation |
|---|---|---|---|
| IMU drift causing wrong lap count | Medium | High | Accumulated yaw with 1080° threshold (not turn counting alone) |
| HuskyLens misdetects pillar color | Low | High | Largest-area block selection; 300 ms avoidance timeout |
| Battery voltage drop during run | Medium | Medium | Pre-run voltmeter check; separate motor and logic rails |
| Narrow corridor causes wall collision | Medium | High | Adaptive speed reduction + emergency steering overrides |
| Servo center offset causes drift | Low | Medium | IMU gyro correction on straight sections |
| Chassis deformation under impact | Low | Medium | 3 mm wall thickness, triangular gussets at stress points |

---

## Criterion 5 — Repository & Reproducibility

### How to Build & Run

#### Hardware requirements

See [Components & Bill of Materials](#components--bill-of-materials) below.

#### Software setup

1. Install **Arduino IDE** (v1.8.x or v2.x).
2. Install the following libraries via Library Manager:
   - `MPU6050_light` by rfetick
   - `HUSKYLENS` by DFRobot
   - `Servo` (built-in)
3. Clone this repository:
   ```bash
   git clone https://github.com/christopherperezcortes/WRO-2026-Future-Engineers.git
   ```
4. Open `src/open_challenge/open_challenge.ino` for the Open Challenge code.
5. Open `src/obstacle_challenge/obstacle_challenge.ino` for the Obstacle Challenge code.
6. Connect Arduino Nano via Mini USB.
7. Select **Board:** Arduino Nano | **Processor:** ATmega328P | **Port:** (your port).
8. Click **Upload**.

#### Startup procedure (competition)

1. Place robot in starting zone, completely **powered off** (rule 9.6).
2. Power on with main switch. Robot initializes IMU (~3 sec, do not move).
3. Serial monitor shows `=== SISTEMA LISTO — WRO FUTURE ENGINEERS ===`.
4. Wait for judge's signal.
5. Press **Start button** (digital pin D12, active LOW) — robot begins.

#### HuskyLens training (one-time per competition environment)

1. Connect HuskyLens to USB and open HUSKYLENS app on phone.
2. Set mode to **Color Recognition**.
3. Point at red pillar → press **Learn** (ID 1).
4. Point at green pillar → press **Learn** (ID 2).
5. Disconnect and mount on robot.

---

### Components & Bill of Materials

| # | Component | Qty | Unit Price (USD) | Total (USD) | Link |
|---|---|---|---|---|---|
| 1 | HuskyLens AI Camera (SEN0305) | 1 | 35.00 | 35.00 | [Buy](https://www.dfrobot.com/product-2995.html) |
| 2 | Arduino Nano (ATmega328P) | 1 | 8.00 | 8.00 | [Buy](https://www.steren.com.mx/placa-de-desarrollo-nano.html) |
| 3 | HC-SR04 Ultrasonic Sensor | 3 | 3.00 | 9.00 | [Buy](https://uelectronics.com/producto/sensor-ultrasonico-hc-sr04/) |
| 4 | MPU6050 IMU (6-DOF) | 1 | 4.00 | 4.00 | [Buy](https://uelectronics.com/producto/imu-mpu6050-6-grados-de-libertad/) |
| 5 | TB6612FNG Motor Driver | 1 | 5.00 | 5.00 | [Buy](https://uelectronics.com/producto/doble-puente-h-tb6612fng/) |
| 6 | Mini 560 Step-Down Regulator (5V/3A) | 1 | 4.00 | 4.00 | [Buy](https://uelectronics.com/producto/mini-560-regulador-step-down/) |
| 7 | SG90 Servo Motor | 1 | 3.00 | 3.00 | Local supplier |
| 8 | DC Gearmotor (RC car base) | 1 | 15.00 | 15.00 | Local supplier |
| 9 | 7.4V 2S LiPo Battery | 1 | 20.00 | 20.00 | Local supplier |
| 10 | Mini Digital Voltmeter | 1 | 3.00 | 3.00 | [Buy](https://www.amazon.com.mx/dp/B07P1RV5B1) |
| 11 | PLA filament (chassis) | ~200 g | 0.02/g | 4.00 | Local |
| 12 | LEGO Technic rack 1×13 (64781) | 1 | 3.13 | 3.13 | BrickLink |
| 13 | Miscellaneous (wires, connectors, pins) | — | — | 5.00 | — |
| | **💵 Total Estimated Cost** | | | **~118 USD** | |

---

## Repository Structure

```
WRO-2026-Future-Engineers/
├── README.md                  ← This file (≥5000 characters)
├── src/
│   ├── open_challenge/
│   │   └── open_challenge.ino ← Open Challenge Arduino code
│   └── obstacle_challenge/
│       └── obstacle_challenge.ino ← Obstacle Challenge code
├── schemes/
│   ├── wiring_diagram.pdf
│   └── wiring_diagram.png
├── models/
│   ├── chassis_v3.stl
│   ├── servo_mount.stl
│   └── front_axle_module.stl
├── v-photos/
│   ├── front.jpg
│   ├── back.jpg
│   ├── left.jpg
│   ├── right.jpg
│   ├── top.jpg
│   └── bottom.jpg
└── t-photos/
    ├── team_official.jpg
    └── team_funny.jpg
```

---

## References

- [WRO 2026 Future Engineers – General Rules (PDF)](https://wro-association.org/wp-content/uploads/WRO-2026-Future-Engineers-Self-Driving-Cars-General-Rules.pdf)
- [WRO 2026 Engineering Journal Rubric (PDF)](https://wro-association.org)
- [WRO GitHub Template Repository](https://github.com/World-Robot-Olympiad-Association/wro2022-fe-template)
- [HuskyLens Arduino Library – DFRobot](https://github.com/HuskyLens/HUSKYLENSArduino)
- [MPU6050_light Library](https://github.com/rfetick/MPU6050_light)
- [TB6612FNG Datasheet](https://www.sparkfun.com/datasheets/Robotics/TB6612FNG.pdf)
- [WRO 2025 Los Grises Superiores Repository](https://github.com/christopherperezcortes/WRO-2025-Future-Engineers) *(previous season)*

---

*End of README.md — Team Los Grises Superiores | WRO 2026 Future Engineers*

*Repository must remain public for at least 12 months after the competition (WRO Rule 7).*

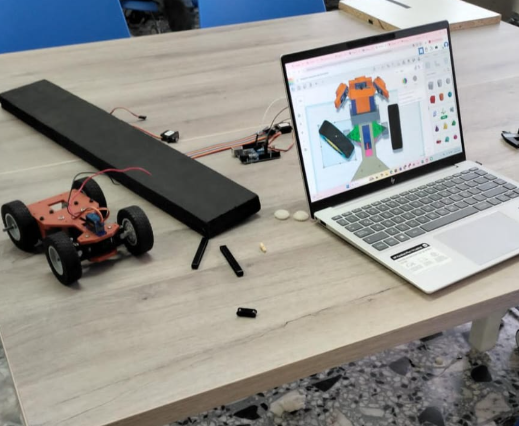
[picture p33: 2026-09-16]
evidences/evidence1.png

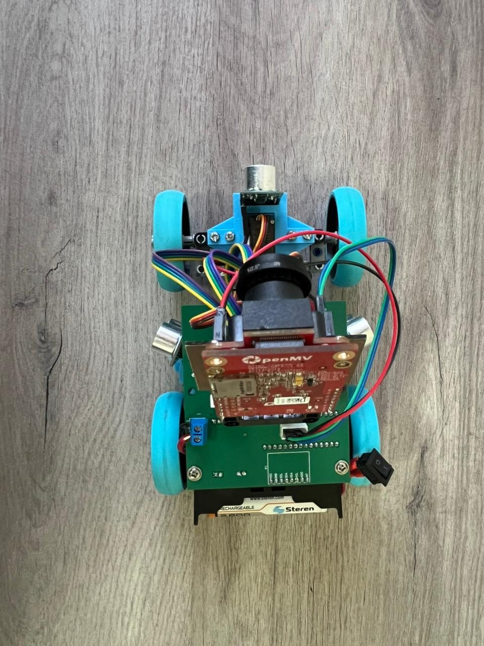
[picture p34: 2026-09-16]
prototype/Top.jpeg

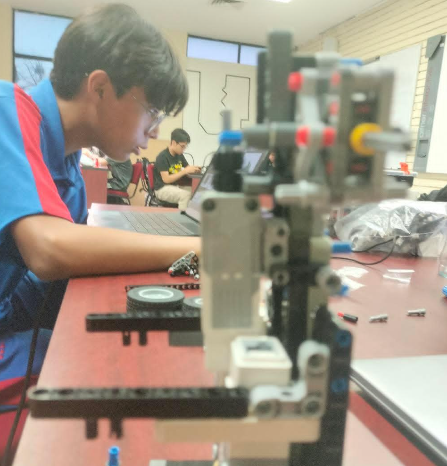
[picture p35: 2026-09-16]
evidences/evidence4.png

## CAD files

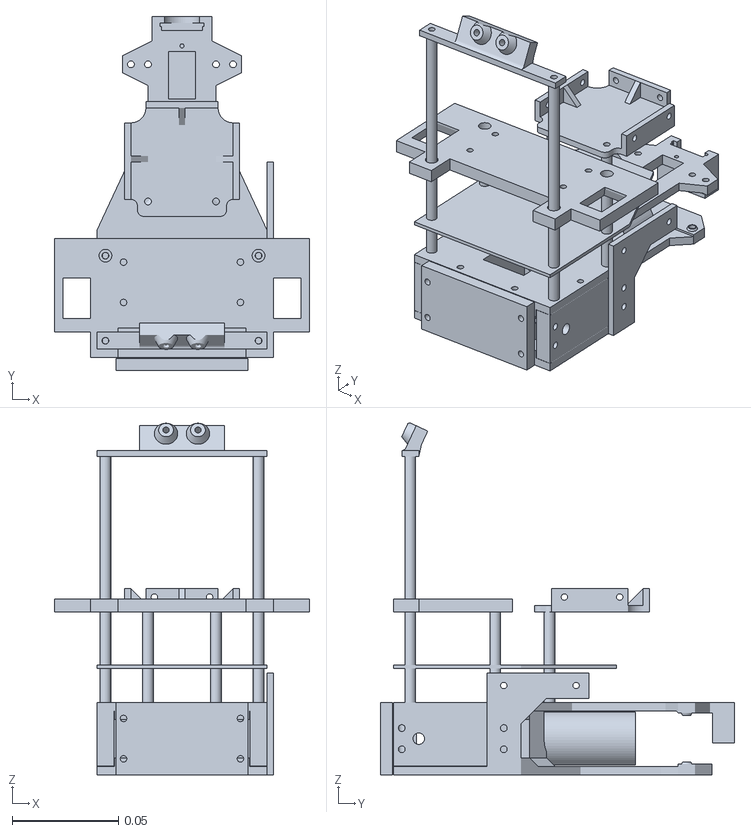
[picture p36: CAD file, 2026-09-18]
models/final_design.stl
0.12 x 0.167 x 0.165

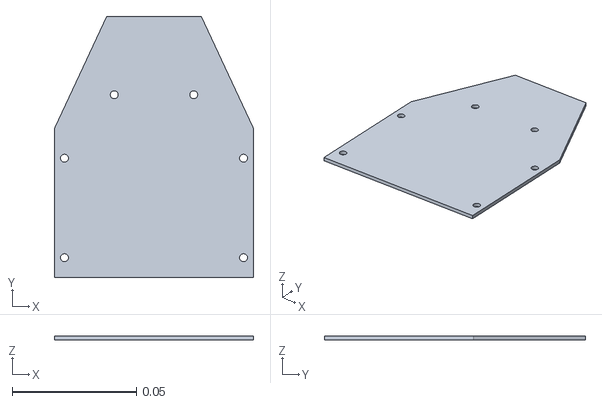
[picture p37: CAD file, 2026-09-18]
models/Part Studio 1 - Part 10.stl
0.08 x 0.105 x 0.0016

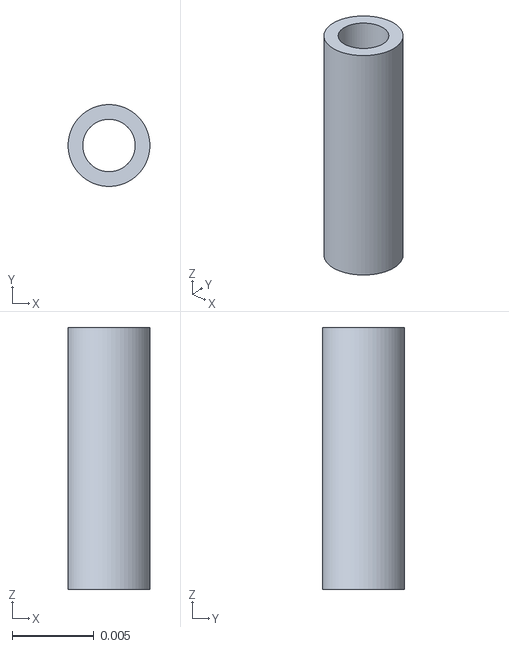
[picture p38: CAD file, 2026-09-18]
models/Part Studio 1 - Surface 15.stl
0.005 x 0.00499 x 0.016

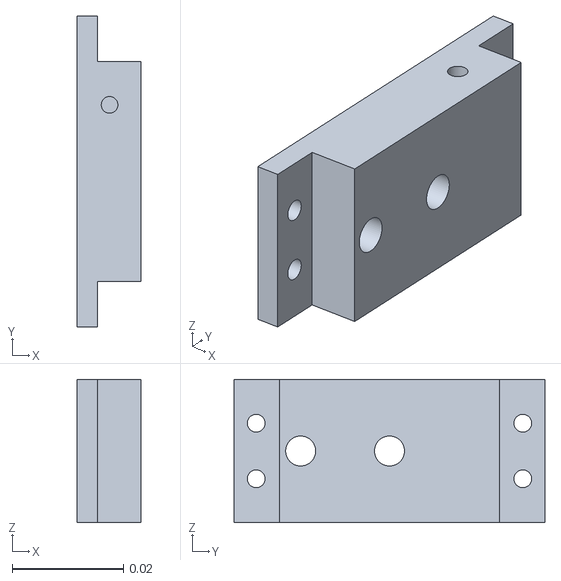
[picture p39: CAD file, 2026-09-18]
models/Part Studio 1 - central izquierdo.stl
0.0116 x 0.056 x 0.0258

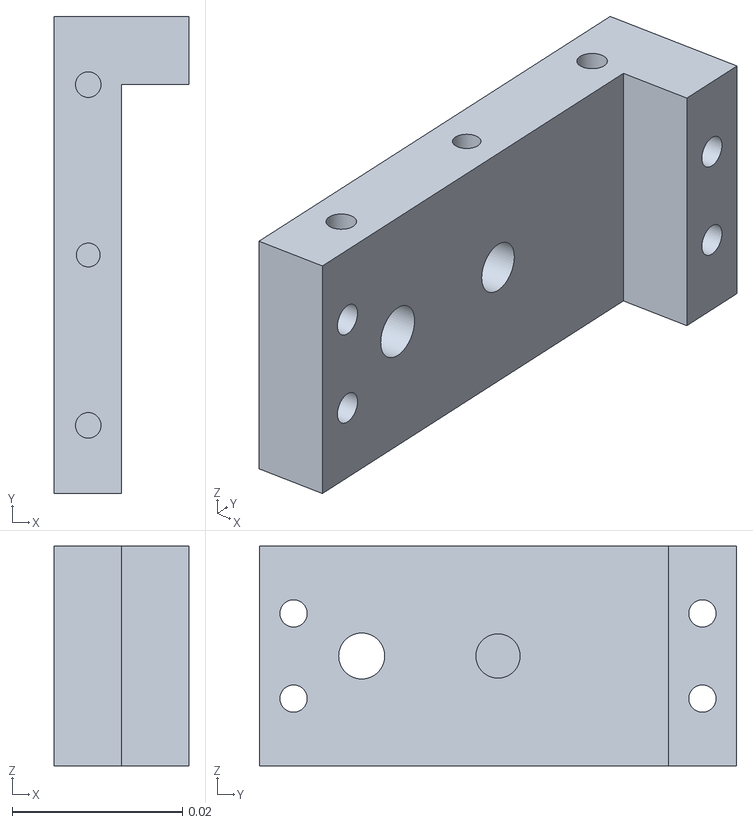
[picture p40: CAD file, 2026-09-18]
models/Part Studio 1 - externo izquierdo.stl
0.0158 x 0.056 x 0.0258

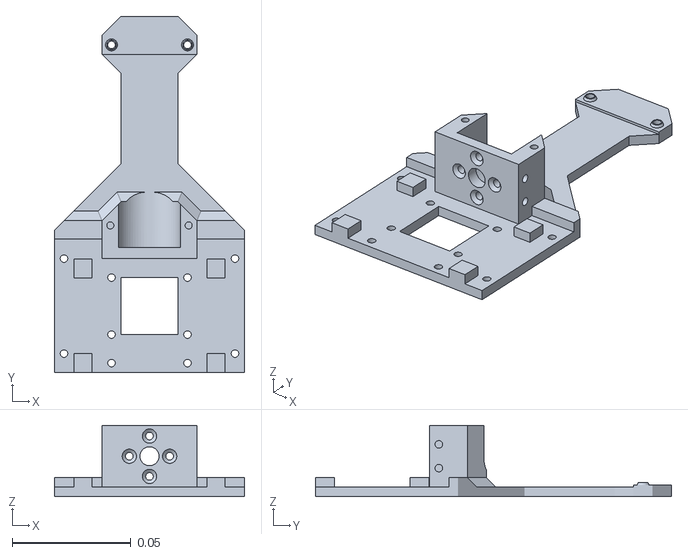
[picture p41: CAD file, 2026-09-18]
models/Part Studio 1 - cuerpo inferior.stl
0.08 x 0.15 x 0.03

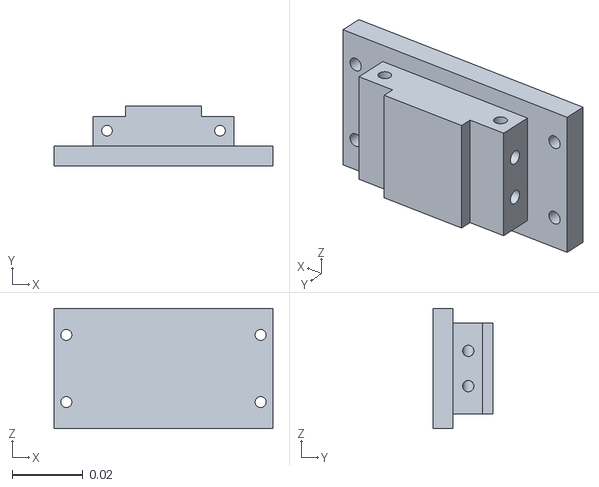
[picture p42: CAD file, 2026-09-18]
models/Part Studio 1 - soporte tracero.stl
0.062 x 0.017 x 0.034

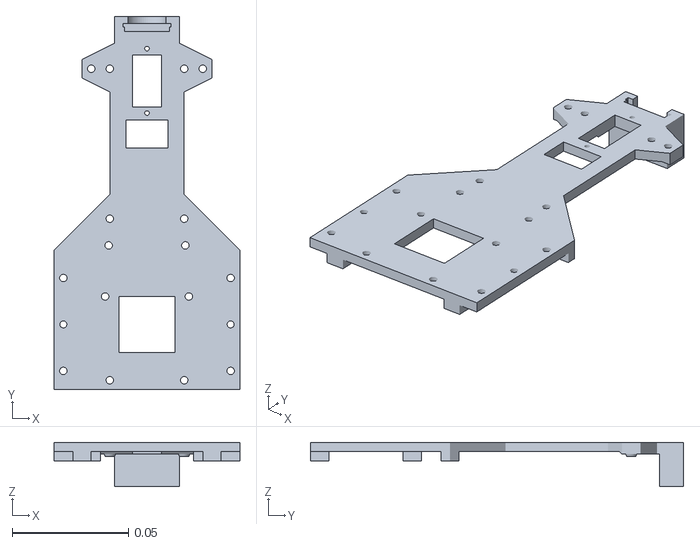
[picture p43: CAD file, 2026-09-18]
models/Part Studio 1 - cuerpo superior.stl
0.08 x 0.161 x 0.019

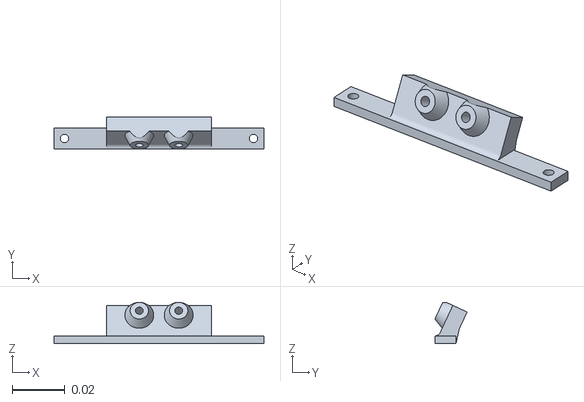
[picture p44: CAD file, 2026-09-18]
models/Part Studio 1 - Part 15.stl
0.08 x 0.0123 x 0.0158

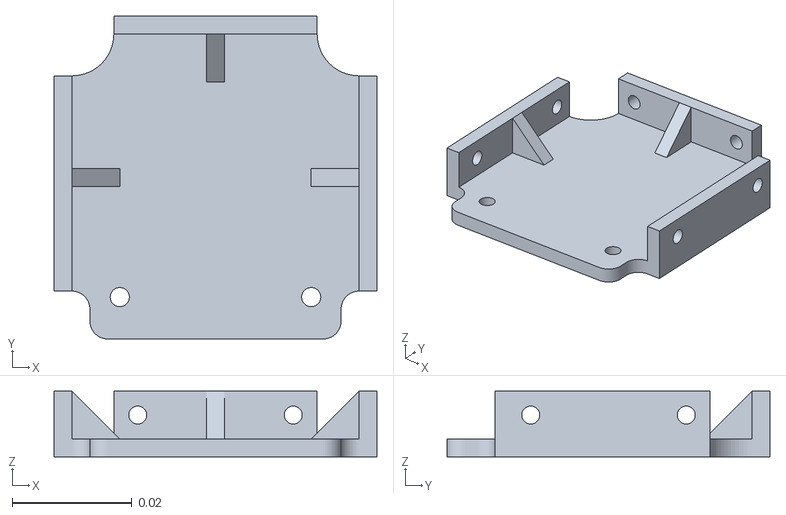
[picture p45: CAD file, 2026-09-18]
models/Part Studio 1 - Part 16.stl
0.054 x 0.054 x 0.011

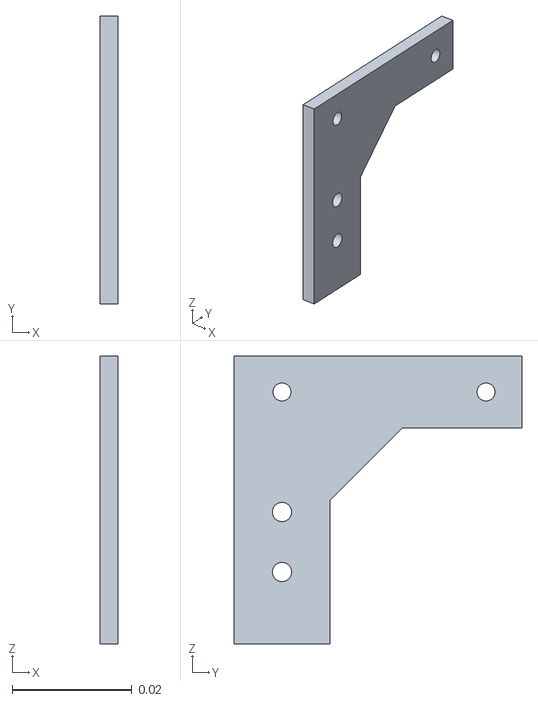
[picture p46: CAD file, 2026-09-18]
models/Part Studio 1 - Part 14.stl
0.003 x 0.048 x 0.048

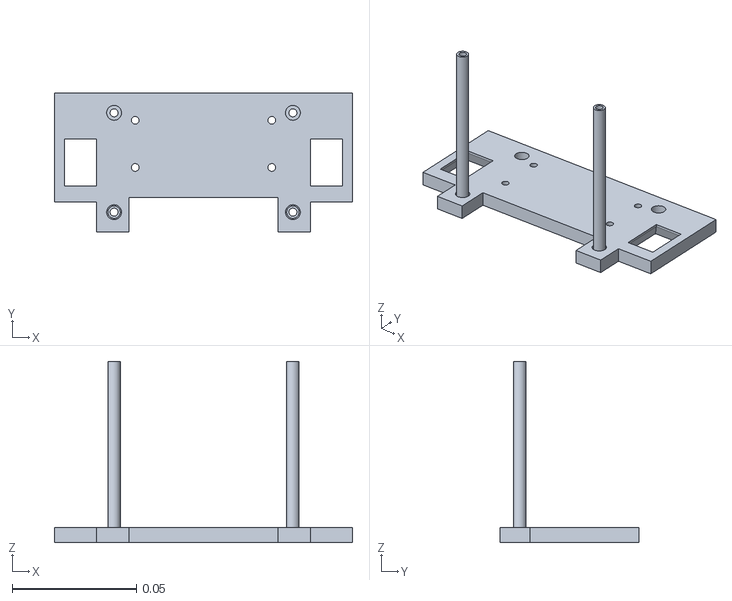
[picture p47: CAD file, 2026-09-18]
models/Part Studio 1 - Part 11.stl
0.12 x 0.056 x 0.073

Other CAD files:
models/Part Studio 1 - central derecho.stl
models/Part Studio 1 - Surface 18.stl
models/Part Studio 1 - externo derecho.stl

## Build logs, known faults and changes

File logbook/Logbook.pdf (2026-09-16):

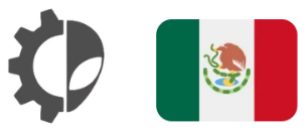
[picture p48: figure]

Logbook — Team Superiores

WRO Future Engineers — National Tijuana

Team Details

- Team: Superiores
- Members:

Christopher Pérez Cortés: A recent addition to the Robotics Club at the "Profr. Moisés Sáenz Garza" Escuela Normal Superior; he joined the team after completing an intensive robotics course. Currently in his third year of secondary school, he possesses skills in electronics, programming, and 3D modeling; this is his first time participating in a WRO tournament.

Bárbara Daiana García Balboa: A member of the Robotics Club at the "Profr. Moisés Sáenz Garza" Escuela Normal Superior for the past six months; she joined the team to participate in WRO 2026 for the first time. She became a member after completing two intensive robotics training courses.

- Programming Language: C++
- Microcontroller: Arduino Uno
- Sensors: 5 ultrasonic (2 right, 2 left, 1 front), open camera (OpenMV)
- 3D Design: Tinkercad

Entry 1 — Early March

Stage: Preparation for online tournament

The team began its preparation aiming for an online tournament. In this first stage, the robot was built entirely with LEGO pieces.

In the online tournament, the team managed to complete the Open Challenge, but failed to complete the Obstacle Challenge (the challenge that involved dodging green and red blocks).

As the weeks went by, it was detected that the LEGO structure took up too much space, which made the internal organization of the components (motors, wiring, sensors) difficult. As a solution, the team decided to migrate toward 3D design and printing of parts (modeled in Tinkercad), achieving a more compact and better-organized structure than the original LEGO version.

Entry 2 — Weekly progress (hardware improvements)

Stage: Iterative robot improvements

As the weeks progressed, several key improvements were made to the robot's components:

- Camera: a HuskyLens was initially used; it was replaced by an open camera (OpenMV), seeking better performance for obstacle/color detection.
- Servomotor: a 2.2 kgf Steren servomotor was swapped for an SG90, adjusting the steering system to the new design needs.

Incidents and solutions:

- The 3D-designed parts did not fit correctly with the motors and the servomotor. Solution: the parts were sanded down to give them the necessary clearance.
- To implement the Ackermann steering strategy, a LEGO piece was included as part of the mechanism; additionally, two pieces were cut and an extra 3D-printed piece was manufactured to complete the assembly.
- The circuit board (PCB) burned out on one occasion because the batteries were inserted backward. Solution: a new board was installed and completely re-soldered.

Detection and control components:

- 5 ultrasonic sensors: two on the right, two on the left, and one in front.
- Microcontroller: Arduino Uno.

Entry 3 — Week before the competition (current)

Stage: Final testing, documentation, and backups

One week away from the national competition in Tijuana, the team is in the home stretch:

- Programming (C++): the programming logic is already working correctly, both for the Open Challenge and the Obstacle Challenge. Pending: fine calibration so the robot returns exactly to its starting position (it currently drifts a bit).
- Documentation: technical documentation for the project is being drafted and organized.
- Spare parts: spare cables, 3D-printed parts, and other components are being manufactured as a contingency plan in case of failures during the competition.

- Support: the team has the backing of an advisor professor throughout the entire process.

Plan for the upcoming days:

- Continue programming tests to verify that the entire system works consistently.
- Keep manufacturing spare parts for critical components.
- Fine-tune the robot's calibration to eliminate trajectory deviations.

## Robot Photos :

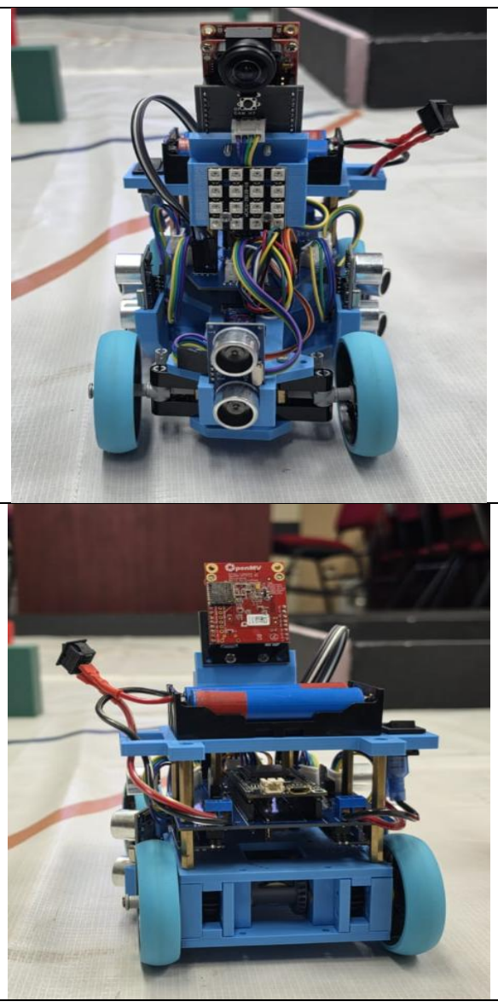
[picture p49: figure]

## Front

## Back

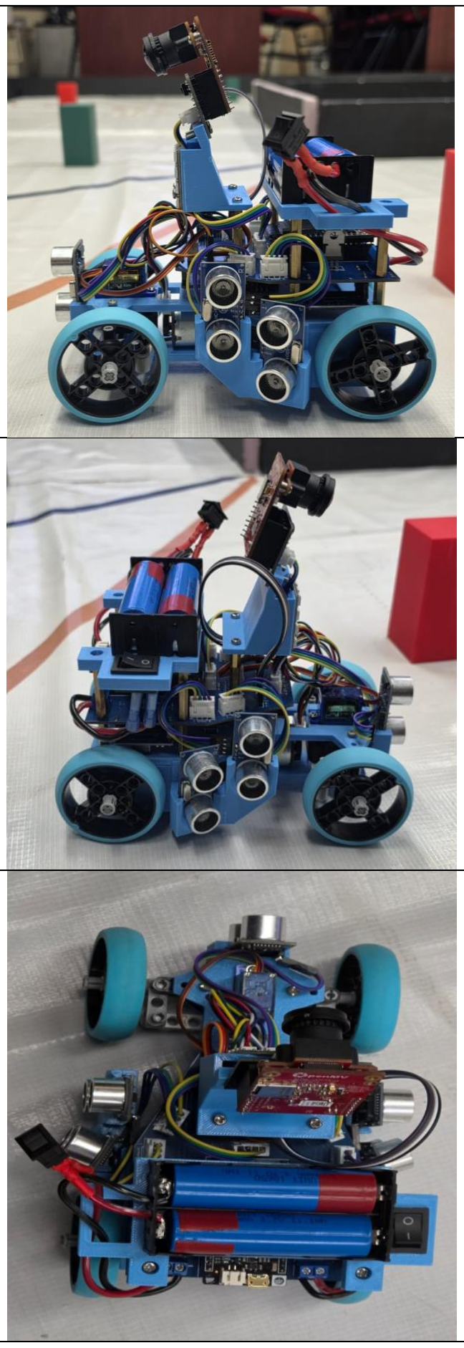
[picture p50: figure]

## Left

## Right

## Top

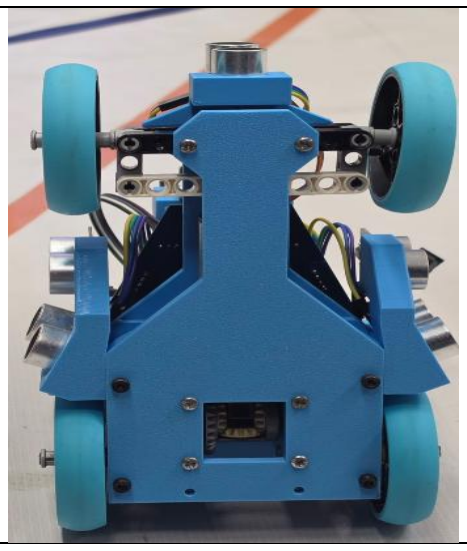
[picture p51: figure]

## Bottom

## We are currently striving to become an ever-larger team, and we eagerly await the day of the

competition.

## - Superiores

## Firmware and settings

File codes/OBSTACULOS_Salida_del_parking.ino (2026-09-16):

/*
  ESP32_Obstaculos_OpenMV_3_Vueltas
  Obstaculos para el robot de India con camara OpenMV.

  Variante independiente: conserva la navegacion y la reaccion a pilares,
  sale del estacionamiento, completa tres vueltas y se detiene.

  Es gemelo de los programas HuskyLens: conserva la misma ley de control,
  los mismos pines del robot y una sola orden de servo y motor por ciclo.
  La unica diferencia importante es la camara: OpenMV envia por UART el ID,
  la posicion y el area del pilar detectado.

  Formato compatible con color_corner_v6.py:
    ID,X,Y,AREA,ROI,COLISION,PARED_NEGRA,PARKING,X_PARKING,AREA_PARKING,
    HUECO_PARKING,X_HUECO,ANCHO_HUECO\n
    ID 3 = verde, ID 5 = rojo, ID 0 = sin pilar.
    X llega normalizada de -100 (izquierda) a 100 (derecha).

  Cableado UART2 a 3.3 V:
    OpenMV TX -> FireBeetle D2 / GPIO25 (RX)
    OpenMV RX <- FireBeetle D3 / GPIO26 (TX, opcional)
    OpenMV GND -- FireBeetle GND

  El Nano de ultrasonicos y el BNO085 siguen en I2C IO21/IO22 a 50 kHz.
  La camara usa UART a 19200 baudios y no comparte el bus I2C.
*/

#include <Arduino.h>
#include <Wire.h>
#include <Adafruit_BNO08x.h>
#include <Preferences.h>
#include <ctype.h>
#include <string.h>
#include <math.h>

// ====================================================================
//                  VARIABLES PARA CALIBRAR EL ROBOT
// ====================================================================

// Los Kp del pasillo y de la camara se ajustan aqui. Despues hay que volver
// a cargar el programa al ESP32. Ningun valor guardado en la memoria puede
// reemplazarlos. Los demas parametros conservan sus ajustes opcionales por
// monitor serie.

// ------------------------- Velocidad --------------------------------

// Arath rueda al 40 %. La V2 de India rueda al 70 %, pero esa velocidad
// esta calibrada contra sus maniobras de rescate, que aqui no existen.
// Confirma la trayectoria a 40 y sube de cinco en cinco.
constexpr uint8_t VELOCIDAD_DEFECTO = 70;

// El sentido fisico del motor de este robot sale invertido.
constexpr bool INVERTIR_DIRECCION_MOTOR = true;

// ---------------------- Direccion por pasillo -----------------------

// diferencia = (S1 + S2) - (S4 + S5), en centimetros.
// S1 y S2 miran a la izquierda, S4 y S5 a la derecha.
//
// Control P del pasillo:
//   error = izquierda - derecha
//   correccion = Kp * error
// Arath: angulo = 90 - 0.18 * error, con tope de 18 grados.
constexpr float KP_PASILLO = 4.0f;  // <--- AJUSTAR KP DE PASILLO AQUI
constexpr float TOPE_PASILLO_DEFECTO = 30.0f;

// Cambiar a 1 si el robot se pega a la pared en vez de separarse.
constexpr int8_t DIRECCION_SERVO_PASILLO = -1;

// Recorte de los laterales antes de restar. Ver la nota del encabezado.
constexpr float MAXIMA_DISTANCIA_LATERAL_CM = 150.0f;

// ----------------------- Direccion por camara -----------------------

// Valores de la copia estable de evasion de obstaculos.
// Rojo a la izquierda de la imagen -> el robot pasa por la derecha.
constexpr float OBJETIVO_X_DEFECTO = 45.0f;
constexpr float KP_CAMARA = 1.0f;  // <--- AJUSTAR KP DE CAMARA AQUI
constexpr float TOPE_CAMARA_DEFECTO = 30.0f;

// Cambiar a -1 si el robot rebasa por el lado equivocado.
constexpr int8_t DIRECCION_SERVO_CAMARA = 1;

// IDs enviados por OPENMV/color_corner.py.
constexpr uint8_t ID_ROJO = 5;
constexpr uint8_t ID_VERDE = 3;

// El firmware OpenMV ya filtra blobs pequenos. Este segundo filtro evita
// usar como objetivo una deteccion con area casi nula.
constexpr uint16_t AREA_MINIMA_PILAR_PX = 30;

// Una sola trama sin pilar no debe devolver el volante al control de pasillo.
// Se confirma la perdida visual durante dos tramas consecutivas; una nueva
// deteccion valida reemplaza inmediatamente la anterior.
constexpr uint8_t TRAMAS_PERDIDAS_PARA_SOLTAR_PILAR = 2;

// Despues de rebasar un pilar rojo o verde, el robot se detiene brevemente.
// Durante este tiempo OpenMV y los sensores siguen trabajando; si aparece el
// siguiente pilar, el servo se acomoda antes de reanudar el avance.
constexpr unsigned long PAUSA_DESPUES_OBSTACULO_MS = 500;

// --------------------------- Mision ---------------------------------

constexpr uint8_t VUELTAS_OBJETIVO = 3;
constexpr uint8_t VUELTAS_ANTES_BUSQUEDA_ROSA = 3;
constexpr bool HABILITAR_ESTACIONAMIENTO = false;
constexpr float GRADOS_POR_VUELTA = 360.0f;
constexpr uint8_t ESQUINAS_PARA_TERMINAR = VUELTAS_OBJETIVO * 4;
constexpr float GRADOS_POR_ESQUINA = 90.0f;

// Conteo robusto tomado de ESP32_Open_Optimizado: la primera curva fija el
// sentido de la ronda y cada cuarto de vuelta debe quedar confirmado durante
// varias lecturas. La histeresis impide contar dos veces por ruido del BNO085.
constexpr float GRADOS_PARA_FIJAR_SENTIDO_VUELTA = 45.0f;
constexpr float HISTERESIS_CONTEO_VUELTA_GRADOS = 3.0f;
constexpr uint8_t MUESTRAS_PARA_CONFIRMAR_ESQUINA = 3;

// Al completar la esquina 12 todavia falta recorrer el tramo desde esa
// esquina hasta la posicion de salida. Igual que en ESP32_Open_Optimizado,
// el ancho inicial del pasillo selecciona el tiempo de avance final.
constexpr uint8_t MUESTRAS_PARA_CLASIFICAR_PASILLO = 10;
constexpr uint16_t UMBRAL_PASILLO_ANCHO_MM = 1000;
constexpr unsigned long DURACION_AVANCE_FINAL_PASILLO_ANCHO_MS = 250;
constexpr unsigned long DURACION_AVANCE_FINAL_PASILLO_ANGOSTO_MS = 2500;

// El encoder aprende la distancia real: salida -> primera esquina 4 y las
// dos vueltas completas siguientes. Con esos datos calcula cuantos pulsos
// faltan desde la esquina 12 hasta el punto exacto de salida.
constexpr uint8_t DIFERENCIA_MAXIMA_VUELTAS_ENCODER_PORCENTAJE = 35;
constexpr unsigned long MAXIMO_AVANCE_FINAL_ENCODER_MS = 6000;
constexpr unsigned long FRENO_FINAL_TRES_VUELTAS_MS = 250;

// ------------------ Salida inicial del estacionamiento -------------
// S3 mira al frente; S1 y S5 comparan el espacio a izquierda y derecha.
// El monitor serie muestra mm/10 sin decimales: 21..29 mm aparece como 2 cm.
// Frenar a 30 mm da margen al motor y no exige un eco exacto de 20 mm.
constexpr uint16_t FRENTE_OBJETIVO_SALIDA_MM = 30;
// Si el HC-SR04 pierde el eco despues de ver la pared a 5 cm o menos,
// tratamos esa perdida como llegada al limite cercano.
constexpr uint16_t FRENTE_ECO_CERCANO_SALIDA_MM = 50;
constexpr unsigned long PAUSA_FRENTE_SALIDA_MS = 500;  // 0.5 s
// El retroceso se confirma con S3 al alejarse 70 mm de la lectura de frenado.
constexpr uint16_t RETROCESO_SALIDA_MM = 62;
constexpr uint8_t VELOCIDAD_AVANCE_SALIDA = 18;
constexpr uint8_t VELOCIDAD_REVERSA_SALIDA = 18;
constexpr uint8_t VELOCIDAD_GIRO_SALIDA = 25;
// Tres movimientos iniciales de 2 s: giro, reversa recta y segundo giro.
constexpr unsigned long TIEMPO_GIRO_SALIDA_MS = 1000;
constexpr unsigned long TIEMPO_REVERSA_CENTRO_INTERMEDIA_MS = 1400;
constexpr unsigned long TIEMPO_SEGUNDO_GIRO_SALIDA_MS = 2500;
constexpr unsigned long PAUSA_SERVO_CENTRO_SALIDA_MS = 200;
constexpr unsigned long MAXIMO_RECUPERAR_RUMBO_SALIDA_MS = 1000;
constexpr unsigned long MAXIMA_EDAD_RUMBO_SALIDA_MS = 500;
constexpr unsigned long PAUSA_SERVO_GIRADO_MS = 200;
constexpr unsigned long MAXIMO_AVANCE_SALIDA_MS = 12000;
constexpr unsigned long MAXIMO_REVERSA_SALIDA_MS = 5000;
constexpr unsigned long MAXIMO_ELEGIR_LADO_MS = 1000;
constexpr uint16_t FRENTE_EMERGENCIA_GIRO_MM = 30;

// Tras el segundo giro, el BNO085 confirma el rumbo original antes del coleo.
constexpr float TOLERANCIA_RUMBO_SALIDA_GRADOS = 5.0f;

// Despues de enderezar el rumbo, el robot hace un coleo para terminar de
// salir del cajon: avanza girando al lado contrario, retrocede girando de
// vuelta al lado original, y termina retrocediendo con las ruedas centradas.
constexpr unsigned long DURACION_AVANCE_CONTRARIO_SALIDA_MS = 2000;  // 2 s
constexpr unsigned long DURACION_RETROCESO_GIRO_SALIDA_MS = 2000;    // 2 s
constexpr unsigned long DURACION_RETROCESO_CENTRO_SALIDA_MS = 3000;  // 3 s


// Las tres primeras vueltas conservan exactamente el control normal. Al
// comenzar la cuarta no se frena: se activa la busqueda rosa y el robot sigue
// avanzando. Si no encuentra el estacionamiento, se detiene al completar la 4.

// ------------------ Final y busqueda de estacionamiento ------------

// Convencion del BNO085. Cambiar a -1 solamente si en telemetria los giros
// a la izquierda hacen disminuir giroAcumuladoGrados.
constexpr int8_t SIGNO_BNO_GIRO_IZQUIERDA = 1;

// En este robot un angulo mayor de 90 dirige las ruedas a la derecha.
// Cambiar a -1 si fisicamente ocurre lo contrario.
constexpr int8_t SIGNO_SERVO_DERECHA = 1;

// La cuarta vuelta conserva la velocidad y la conduccion normales hasta que
// la camara confirma el rosa.
constexpr uint8_t TRAMAS_PARED_ESTACIONAMIENTO = 3;
constexpr uint8_t TRAMAS_HUECO_ESTACIONAMIENTO = 2;
constexpr unsigned long INTERVALO_MODO_ESTACIONAMIENTO_MS = 250;
constexpr unsigned long MAXIMO_BUSQUEDA_ESTACIONAMIENTO_MS = 45000;
constexpr int16_t ZONA_CENTRAL_LADO_PARKING_X = 12;

// Despues de confirmar el rosa, la camara deja de dirigir por color y estos
// valores mantienen al robot a 8..10 cm mientras alinea las llantas.
constexpr uint16_t DISTANCIA_EXTERIOR_MINIMA_MM = 80;
constexpr uint16_t DISTANCIA_EXTERIOR_OBJETIVO_MM = 90;
constexpr uint16_t DISTANCIA_EXTERIOR_MAXIMA_MM = 100;
constexpr uint16_t DISTANCIA_MAXIMA_SEGUIMIENTO_EXTERIOR_MM = 300;
constexpr float KP_PARED_EXTERIOR_GRADOS_POR_MM = 0.20f;
constexpr float TOPE_PARED_EXTERIOR_GRADOS = 22.0f;

// Deteccion del primer delimitador y del hueco con S1 o S5, segun el lado
// que haya guardado la camara. La histeresis evita alternar por ruido.
constexpr uint16_t UMBRAL_DELIMITADOR_PARKING_MM = 260;
constexpr uint16_t UMBRAL_HUECO_PARKING_MM = 320;
constexpr uint16_t SALTO_MINIMO_HUECO_PARKING_MM = 80;
constexpr unsigned long BORDE_ESTABLE_PARKING_MS = 75;

// Entrada como en el video: el lateral localiza el delimitador y su borde,
// se alinea el eje delantero y se hacen solo dos movimientos de direccion:
// arco hacia el cajon y contraarco hasta recuperar el rumbo original.
constexpr uint8_t VELOCIDAD_APROXIMACION_PARKING = 20;
constexpr uint8_t VELOCIDAD_MANIOBRA_PARKING = 18;
constexpr unsigned long AVANCE_MINIMO_ALINEAR_LLANTAS_MS = 550;
constexpr uint32_t PULSOS_MINIMOS_ALINEAR_LLANTAS = 4;
constexpr unsigned long MAXIMO_ALINEAR_LLANTAS_MS = 1800;
constexpr float ANGULO_SERVO_PARKING_GRADOS = 38.0f;
constexpr float CAMBIO_RUMBO_ENTRADA_PARKING_GRADOS = 55.0f;
constexpr float TOLERANCIA_RUMBO_FINAL_PARKING_GRADOS = 3.0f;
constexpr uint16_t MARGEN_FRONTAL_FINAL_PARKING_MM = 70;
constexpr uint16_t DISTANCIA_FRONTAL_EMERGENCIA_PARKING_MM = 45;
constexpr uint16_t DISTANCIA_LATERAL_EMERGENCIA_PARKING_MM = 45;
constexpr unsigned long MAXIMO_LOCALIZAR_DELIMITADOR_MS = 6000;
constexpr unsigned long MAXIMO_ESPERAR_HUECO_MS = 3500;
constexpr unsigned long MAXIMO_ARCO_PARKING_MS = 4500;
constexpr unsigned long AVANCE_MINIMO_DENTRO_PARKING_MS = 900;
constexpr uint32_t PULSOS_MINIMOS_DENTRO_PARKING = 4;
constexpr unsigned long MAXIMO_CENTRADO_PARKING_MS = 4500;
constexpr unsigned long FRENO_FINAL_PARKING_MS = 180;

// ------------------- Escape por obstaculo frontal -----------------

// Misma estrategia del programa Open: S3 activa una reversa con histeresis.
// Primero se corta el motor, despues se retrocede guiando el volante segun el
// sentido acumulado de la ronda y finalmente se hace otra pausa antes de
// recuperar el avance normal por camara/pasillo.
// La copia estable reaccionaba a 35 cm y recuperaba el avance a 50 cm. Se
// conservan dos lecturas consecutivas para rechazar un eco aislado.
constexpr uint8_t TRAMAS_CONFIRMAR_ESCAPE_FRONTAL = 2;
constexpr uint16_t DISTANCIA_FRENTE_RETROCESO_MM = 350;
constexpr uint16_t DISTANCIA_FRENTE_SALIDA_RETROCESO_MM = 500;
constexpr uint8_t VELOCIDAD_REVERSA_ESCAPE = 45;
constexpr unsigned long FRENO_ANTES_RETROCESO_MS = 150;
constexpr unsigned long FRENO_DESPUES_RETROCESO_MS = 150;
constexpr unsigned long MAXIMO_RETROCESO_ESCAPE_MS = 2500;
constexpr float UMBRAL_SENTIDO_RETROCESO_GRADOS = 12.0f;
constexpr float ANGULO_GUIA_RETROCESO_GRADOS = 18.0f;

// Evita quedar atrapado repitiendo la reversa frente a la misma pared. Tras
// cuatro intentos consecutivos, avanza despacio con giro firme en el sentido
// de la ronda y despues reinicia el contador de escapes.
constexpr uint8_t MAXIMO_RETROCESOS_CONSECUTIVOS = 4;
constexpr uint8_t VELOCIDAD_SALIDA_FORZADA = 25;
constexpr float ANGULO_SALIDA_FORZADA_GRADOS = 30.0f;
constexpr unsigned long DURACION_SALIDA_FORZADA_MS = 1200;
constexpr unsigned long TIEMPO_DESPEJADO_REINICIAR_RETROCESOS_MS = 1000;

// Cambiar a -1 si el robot gira hacia el lado equivocado al retroceder.
constexpr int8_t DIRECCION_SERVO_REVERSA = 1;

// COLISION ya llega desde OpenMV. Primero reduce velocidad para darle tiempo
// al control de camara; S3 sigue siendo quien autoriza la reversa.
constexpr uint8_t VELOCIDAD_ALERTA_COLISION = 40;
constexpr unsigned long RETENCION_ALERTA_COLISION_MS = 200;

// Un eco perdido durante un solo ciclo conserva la ultima lectura real. Tras
// este margen ya se declara invalida y el control general frena por seguridad.
constexpr unsigned long RETENCION_ULTIMO_ECO_VALIDO_MS = 125;

// ------------------------ Ritmo del ciclo ---------------------------

// 40 Hz. OpenMV se recibe sin bloquear por UART y el paquete del Nano tarda
// unos 2 ms, asi que el ciclo cierra con margen de sobra.
constexpr unsigned long PERIODO_CICLO_MS = 25;
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
void loop() {
  const unsigned long ahoraMs = millis();

  if (ahoraMs - ultimoCicloMs < PERIODO_CICLO_MS) {
    return;
  }
  ultimoCicloMs = ahoraMs;

  // ---------------- 1. percepcion ----------------

  actualizarCamara(ahoraMs);

  const bool paqueteSensoresNuevo = leerDistancias(ahoraMs);
  if (paqueteSensoresNuevo) {
    ultimoPaqueteMs = ahoraMs;
    hayDistancias = true;
    actualizarClasificacionPasilloInicial();
  } else if (hayDistancias &&
             ahoraMs - ultimoPaqueteMs > TIMEOUT_SENSORES_MS) {
    hayDistancias = false;
    Serial.println("AVISO: sin paquete del Nano");
  }

  actualizarBno(ahoraMs);
  actualizarSalidaInicial(ahoraMs, paqueteSensoresNuevo);
  actualizarAvanceFinalTresVueltas(ahoraMs);

  // ---------------- 2. arranque de la ronda ----------------

  if (fase == Fase::ESPERANDO &&
      leerPulsosEncoder() >= PULSOS_PARA_ARRANCAR) {
    fase = Fase::RODANDO;
    inicioRondaMs = ahoraMs;
    giroAcumuladoGrados = 0.0f;
    giroConteoVueltasGrados = 0.0f;
    signoGiroVueltas = 0;
    esquinas = 0;
    muestrasConfirmacionEsquina = 0;
    vueltasCompletadas = 0;
    pulsosNetosInicioRonda = leerPulsosEncoderNetos();
    pulsosNetosVuelta1 = 0;
    pulsosNetosVuelta2 = 0;
    pulsosNetosVuelta3 = 0;
    pulsosNetosInicioAvanceFinal = 0;
    pulsosObjetivoAvanceFinal = 0;
    referenciaFinalEncoderValida = false;
    avanceFinalAcumuladoMs = 0;
    pausaDespuesObstaculoActiva = false;
    retrocesosConsecutivos = 0;
    inicioFrenteDespejadoMs = 0;
    ladoParking = 0;
    huecoParkingGuardado = false;
    confirmacionesObstaculoFrontal = 0;
    Serial.println("Ronda iniciada");
  }

  // ---------------- 3. escape por obstaculo frontal ----------------

  actualizarReinicioRetrocesos(ahoraMs);

  if (fasePermiteEscapeFrontal() && frenteActivaEscape()) {
    faseDespuesEscape = fase;
    pilarAlIniciarEscape = pilar;
    if (pilarAlIniciarEscape.color == Color::NINGUNO &&
        colisionVisual != 0) {
      pilarAlIniciarEscape.color = colorDeId(colisionVisual);
      pilarAlIniciarEscape.xCamara = 0.0f;
    }

    if (retrocesosConsecutivos >= MAXIMO_RETROCESOS_CONSECUTIVOS) {
      iniciarSalidaForzadaEscape(ahoraMs);
    } else {
      ++retrocesosConsecutivos;
      fase = Fase::FRENANDO_ESCAPE_FRONTAL;
      inicioFaseMs = ahoraMs;
      confirmacionesObstaculoFrontal = 0;
      inicioFrenteDespejadoMs = 0;
      Serial.print("S3 detecta obstaculo a ");
      Serial.print(distanciasMm[INDICE_FRONTAL] / 10);
      Serial.print(" cm: retroceso ");
      Serial.print(retrocesosConsecutivos);
      Serial.print("/");
      Serial.println(MAXIMO_RETROCESOS_CONSECUTIVOS);
    }
  }

  if (fase == Fase::FRENANDO_ESCAPE_FRONTAL &&
      ahoraMs - inicioFaseMs >= FRENO_ANTES_RETROCESO_MS) {
    fase = Fase::RETROCEDIENDO_ESCAPE_FRONTAL;
    inicioFaseMs = ahoraMs;
    inicioRetrocesoEscapeMs = ahoraMs;
    Serial.print("Escape frontal: reversa al ");
    Serial.print(VELOCIDAD_REVERSA_ESCAPE);
    Serial.print("%, servo=");
    Serial.println(anguloReversaEscape(), 0);
  }

  if (fase == Fase::RETROCEDIENDO_ESCAPE_FRONTAL) {
    if (frenteDespejadoTrasEscape()) {
      if (retrocesosConsecutivos >= MAXIMO_RETROCESOS_CONSECUTIVOS) {
        iniciarSalidaForzadaEscape(ahoraMs);
      } else {
        fase = Fase::FRENO_TRAS_ESCAPE;
        inicioFaseMs = ahoraMs;
        Serial.println("S3 despejado: freno antes de recuperar el avance");
      }
    } else if (ahoraMs - inicioRetrocesoEscapeMs >=
               MAXIMO_RETROCESO_ESCAPE_MS) {
      if (retrocesosConsecutivos >= MAXIMO_RETROCESOS_CONSECUTIVOS) {
        iniciarSalidaForzadaEscape(ahoraMs);
      } else {
        fase = Fase::FRENO_TRAS_ESCAPE;
        inicioFaseMs = ahoraMs;
        Serial.println("Retroceso terminado por tiempo; se intentara avanzar");
      }
    }
  }

  if (fase == Fase::ESPERANDO_DESPEJE_ESCAPE &&
      frenteDespejadoTrasEscape()) {
    fase = Fase::FRENO_TRAS_ESCAPE;
    inicioFaseMs = ahoraMs;
    Serial.println("S3 vuelve a estar libre: preparando avance");
  }

  if (fase == Fase::FRENO_TRAS_ESCAPE &&
      ahoraMs - inicioFaseMs >= FRENO_DESPUES_RETROCESO_MS) {
    fase = faseDespuesEscape;
    inicioFaseMs = ahoraMs;
    if (fase == Fase::AVANCE_LIBRE_ENTRADA) {
      pulsosInicioMovimientoParking = leerPulsosEncoder();
    }
    Serial.println("Escape terminado: continua control por camara/pasillo");
  }

  if (fase == Fase::SALIDA_FORZADA_ESCAPE &&
      ahoraMs - inicioSalidaForzadaEscapeMs >=
          DURACION_SALIDA_FORZADA_MS) {
    fase = faseDespuesEscape;
    inicioFaseMs = ahoraMs;
    inicioFrenteDespejadoMs = 0;
    confirmacionesObstaculoFrontal = 0;
    if (fase == Fase::AVANCE_LIBRE_ENTRADA) {
      pulsosInicioMovimientoParking = leerPulsosEncoder();
    }
    Serial.println(
        "Salida forzada terminada: no habra mas reversa hasta despejar S3");
  }

  // ---------------- 4. busqueda rosa durante la cuarta vuelta -------

  if (fase == Fase::BUSCANDO_ESTACIONAMIENTO) {
    if (confirmacionesParedEstacionamiento >=
        TRAMAS_PARED_ESTACIONAMIENTO) {
      guardarMedicionParking();
      fase = Fase::LOCALIZANDO_PRIMER_DELIMITADOR;
      inicioFaseMs = ahoraMs;
      reiniciarConfirmacionParking();
      Serial.print("Rosa confirmado y guardado x=");
      Serial.print(referenciaParkingXGuardada);
      Serial.print(" area=");
      Serial.print(areaParkingGuardada);
      if (huecoParkingGuardado) {
        Serial.print(" hueco_x=");
        Serial.print(huecoParkingXGuardado);
        Serial.print(" ancho_px=");
        Serial.print(anchoHuecoParkingGuardadoPx);
      } else {
        Serial.print(" hueco=no_visible");
      }
      Serial.print("; cajon al lado ");
      Serial.println(ladoParkingElegido() > 0 ? "derecho" : "izquierdo");
      Serial.println(
          "Rosa confirmado: se ignoran colores y se alinean las llantas");
    } else if (cuartaVueltaSinParkingCompleta(ahoraMs)) {
      iniciarFrenoFinalParking(
          ahoraMs, false,
          "ERROR: no se encontro rosa antes de completar la cuarta vuelta");
    }
  }

  if (fase == Fase::LOCALIZANDO_PRIMER_DELIMITADOR) {
    if (condicionParkingEstable(lecturaPrimerDelimitadorParking(), ahoraMs)) {
      distanciaPrimerDelimitadorMm = distanciasMm[indiceParking90()];
      fase = Fase::ESPERANDO_ENTRADA_HUECO;
      inicioFaseMs = ahoraMs;
      reiniciarConfirmacionParking();
      Serial.print("Primer delimitador junto al robot a ");
      Serial.print(distanciaPrimerDelimitadorMm);
      Serial.println(" mm; buscando su borde final");
    } else if (ahoraMs - inicioFaseMs >=
               MAXIMO_LOCALIZAR_DELIMITADOR_MS) {
      iniciarFrenoFinalParking(
          ahoraMs, false,
          "ERROR: OpenMV vio rosa pero el lateral no encontro delimitador");
    }
  }

  if (fase == Fase::ESPERANDO_ENTRADA_HUECO) {
    if (condicionParkingEstable(lecturaEntradaHuecoParking(), ahoraMs)) {
      fase = Fase::AVANCE_LIBRE_ENTRADA;
      inicioFaseMs = ahoraMs;
      pulsosInicioMovimientoParking = leerPulsosEncoder();
      Serial.println("Borde del rosa confirmado; alineando eje delantero");
    } else if (ahoraMs - inicioFaseMs >= MAXIMO_ESPERAR_HUECO_MS) {
      iniciarFrenoFinalParking(
          ahoraMs, false,
          "ERROR: no se encontro la entrada despues del delimitador rosa");
    }
  }

  if (fase == Fase::AVANCE_LIBRE_ENTRADA) {
    const unsigned long tiempoAlineandoMs = ahoraMs - inicioFaseMs;
    const uint32_t pulsosAlineando =
        leerPulsosEncoder() - pulsosInicioMovimientoParking;
    if (tiempoAlineandoMs >= AVANCE_MINIMO_ALINEAR_LLANTAS_MS &&
        pulsosAlineando >= PULSOS_MINIMOS_ALINEAR_LLANTAS) {
      giroBaseManiobraParkingGrados = giroAcumuladoGrados;
      fase = Fase::ARCO_ENTRADA_FRONTAL;
      inicioFaseMs = ahoraMs;
      Serial.println("Llantas alineadas por encoder: arco hacia el cajon");
    } else if (tiempoAlineandoMs >= MAXIMO_ALINEAR_LLANTAS_MS) {
      iniciarFrenoFinalParking(
          ahoraMs, false,
          "ERROR: el encoder no confirmo el avance para alinear las llantas");
    }
  }

  if (fase == Fase::ARCO_ENTRADA_FRONTAL) {
    if (arcoEntradaFrontalCompleto()) {
      fase = Fase::CONTRAARCO_ENTRADA_FRONTAL;
      inicioFaseMs = ahoraMs;
      Serial.println("Movimiento 2: contraarco para quedar paralelo");
    } else if (ahoraMs - inicioFaseMs >= MAXIMO_ARCO_PARKING_MS) {
      iniciarFrenoFinalParking(
          ahoraMs, false, "ERROR: timeout en arco de entrada al parking");
    }
  }
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

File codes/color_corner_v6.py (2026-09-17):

# ============================================================
# OPENMV FIRMWARE 6
# Detección de pilares rojos y verdes
#
# Cambio respecto a la 5: separacion de MAGENTA y ROJO por la media del
# canal B del blob, no por umbral de pixel. Ver el bloque CLASIFICADOR
# DE COLOR POR MEDIA. La version 5 queda intacta en color_corner.py.
#
# UART:
# ID, X, Y, AREA, ROI, COLISION, PARED_NEGRA,
# PARKING, X_PARKING, AREA_PARKING, HUECO, X_HUECO, ANCHO_HUECO
#
# X siempre conserva la esquina inferior original del color:
# - Verde: esquina inferior izquierda.
# - Rojo: esquina inferior derecha.
# Se transmite mapeada entre -100 y 100. El ESP32 convierte ese
# rango al recorrido angular seguro del servo.
#
# En ROI_HIGH el robot sigue directamente esa esquina.
# En ROI_LOW esa misma esquina sirve para medir la separacion
# respecto al ancho del robot (ROI de colision).
# ROI: 0 = ninguna, 1 = alta, 2 = baja.
#
# ID:
# 0 = Sin detección
# 3 = Verde
# 5 = Rojo
# ============================================================

import sensor
import time
import micropython

from machine import UART

try:
    import binascii
except ImportError:
    import ubinascii as binascii


# ============================================================
# CONFIGURACIÓN GENERAL
# ============================================================

SHOW_DEBUG = True
DRAW_BOXES = True
DRAW_TEXT = True

# Superpone la trayectoria que el ESP32 esta ordenando al robot. El ESP32
# devuelve por UART una linea "T,servo,motor,S1,S2,S3,S4,S5". Esta ayuda es
# solamente visual: no modifica la deteccion ni los datos de control enviados.
SHOW_PATH_PREVIEW = False

PRINT_UART_DATA = True
PRINT_FPS = False

# Imprimir la imagen completa en Base64 reduce mucho los FPS.
PRINT_BASE64_FRAME = False
BASE64_JPEG_QUALITY = 35

# ============================================================
# EXPOSICION
#
# Se quito el valor fijo de 30000 us. Ahora la elige la camara mirando
# la escena real, que es lo que hace el script por defecto del IDE y da
# una imagen con mas contraste y colores mas saturados.
#
# CAMERA_EXPOSURE_US
#   None   -> la elige el automatico y se congela ese valor.
#   30000  -> el valor fijo de antes, por si hay que volver.
#
# CAMERA_LOCK_SETTINGS
#   True   -> ganancia, balance de blancos y exposicion se congelan
#             despues del ajuste inicial. Los colores se quedan
#             quietos durante toda la carrera.
#   False  -> los tres siguen en automatico todo el rato, igual que el
#             script por defecto. La imagen se adapta sola a la luz,
#             pero los umbrales dejan de significar lo mismo de un
#             cuadro al siguiente: al entrar un pilar rojo grande el
#             automatico reacciona y mueve la L de TODO lo demas.
#
# Los umbrales actuales separan rojo y magenta principalmente por B:
# magenta termina en 5 y rojo empieza en 10. Si cambia la exposicion,
# conviene volver a comprobar esa banda muerta con los objetos reales.
# ============================================================

CAMERA_EXPOSURE_US = None

CAMERA_LOCK_SETTINGS = True

# Tiempo que se le da al automatico para converger antes de congelar.
CAMERA_AUTO_SETTLE_MS = 800

# True:
# X se envía normalizada entre -100 y 100.
#
# False:
# X se envía en píxeles entre 0 y 319.
X_AS_NORMALIZED = True

# Permite utilizar los dos umbrales de cada color.
USE_MULTI_RANGES = True


# ============================================================
# VISTA PREVIA DE TRAYECTORIA
# ============================================================

SERVO_CENTER_DEG = 90
SERVO_MAX_CORRECTION_DEG = 40

# Cambiar a -1 si la curva aparece al lado contrario del giro fisico.
PATH_SCREEN_DIRECTION = 1

# La proyeccion es intencionalmente calibrable: no pretende medir distancias
# metricas hasta realizar una calibracion de camara sobre el robot.
PATH_NEAR_Y = 236
PATH_FAR_Y = 86
PATH_NEAR_HALF_WIDTH_PX = 34
PATH_FAR_HALF_WIDTH_PX = 7
PATH_MAX_BEND_PX = 105
PATH_SEGMENTS = 12

TELEMETRY_TIMEOUT_MS = 350
PATH_FRONT_DANGER_MM = 250
PATH_SIDE_DANGER_MM = 180


# ============================================================
# UMBRALES ACTIVOS
# ============================================================

USE_RED_1 = True
USE_RED_2 = False

USE_GREEN_1 = True
USE_GREEN_2 = False

USE_MAGENTA_1 = True
USE_MAGENTA_2 = False


# ============================================================
# REGIONES DE INTERÉS
# Formato: (x, y, ancho, alto)
# ============================================================

ROI_HIGH = (60, 60, 200, 50)
ROI_LOW = (70, 110, 180, 130)
ROI_SIDE_LEFT = (0, 110, 70, 100)
ROI_SIDE_RIGHT = (250, 110, 70, 100)

COLLISION_ROI = (125, 165, 80, 10)

# ROI de calibracion, siempre centrada horizontalmente.
# Cambiar unicamente CENTER_ROI_CENTER_Y para subirla o bajarla:
# 0 es la parte superior y 239 la parte inferior de la imagen.
SHOW_CENTER_ROI = True
CENTER_ROI_WIDTH = 6
CENTER_ROI_HEIGHT = 10
CENTER_ROI_CENTER_Y = 105
# Cada pixel con luminosidad LAB menor o igual a este valor cuenta como negro.
# Subirlo acepta tonos mas claros; bajarlo hace la deteccion mas estricta.
WALL_BLACK_L_MAX = 35
# Porcentaje minimo de pixeles negros dentro del ROI para enviar Wall=1.
WALL_BLACK_MIN_PERCENT = 30

CENTER_ROI = (
    (320 - CENTER_ROI_WIDTH) // 2,
    max(
        0,
        min(
            240 - CENTER_ROI_HEIGHT,
            CENTER_ROI_CENTER_Y - CENTER_ROI_HEIGHT // 2
        )
    ),
    CENTER_ROI_WIDTH,
    CENTER_ROI_HEIGHT
)


# ============================================================
# ZONAS MUERTAS LATERALES
#
# Rechazan falsas detecciones producidas por lineas de pared/esquina. El
# margen crece hacia abajo para seguir la perspectiva de la pista.
# ============================================================

USE_CORNER_DEAD_ZONES = False
CORNER_DEAD_ZONE_TOP_Y = 80
CORNER_DEAD_ZONE_BOTTOM_Y = 214
CORNER_DEAD_ZONE_FAR_MARGIN_PX = 18
CORNER_DEAD_ZONE_NEAR_MARGIN_PX = 58


# ============================================================
# CONFIGURACIÓN UART
# ============================================================

UART_BUS = 3
UART_BAUD = 19200

uart = UART(
    UART_BUS,
    UART_BAUD,
    bits=8,
    parity=None,
    stop=1,
    timeout_char=10
)

micropython.alloc_emergency_exception_buf(200)


# ============================================================
# UMBRALES LAB
#
# Formato:
# (L mínimo, L máximo,
#  A mínimo, A máximo,
#  B mínimo, B máximo)
# ============================================================
# cerca
# lejos

# Bloque rojo real: media aproximada LAB (44, 61, 29).
TH_RED_1 = (15, 85, 40, 100, 10, 75)
TH_RED_2 = (20, 100, 36, 127, 16, 127)

# Bloque verde real: media (55, -29, 4), mediana (54, -29, 0).
TH_GREEN_1 = (35, 75, -50, -15, -20, 25)
TH_GREEN_2 = (34, 72, -74, -18, -128, 127)
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

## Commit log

2026-04-23 Rename Soporte sensor central.png to Soporte_sensor_central.png
2026-04-23 Rename Soporte sensores laterales.png to Soporte_sensores_laterales.png
2026-04-23 Enhance README with PCB implementation and insights
    Added PCB & Wiring Implementation section with images and insights on electrical design improvements.
2026-04-23 Revise PCB section and include engineering insights
    Reorganized PCB & Wiring Implementation section and added Engineering Insight.
2026-04-23 Revise README with updates on chassis and power system
    Updated version history and technical details in README.md to reflect changes in chassis design and electrical architecture. Added insights on issues encountered and solutions implemented during development.
2026-04-23 Change bullet color from 🔹 to 🔷 in README
2026-04-24 Add Real PCB image to README section
2026-04-24 Update print statement from 'Hello' to 'Goodbye'
2026-04-25 Revise README for 2026 robot updates and specifications
    Updated the README to reflect changes in the robot's components and architecture for the WRO 2026 competition, including camera and servo upgrades.
2026-04-25 Remove figure caption for CAD render
    Removed figure caption from the README file.
2026-04-25 Fix typo in 'Complete Assembly' header
2026-09-16 Update README with track challenges and project videos
    Added track challenges and project videos sections to README.
2026-09-16 Enhance README with project overview and chassis design
    Added project overview and chassis design details to README.
2026-09-16 Enhance README with steering system and components details
    Added detailed information about the steering system, robot photos, and components in the README.
2026-09-16 Enhance README with Arduino and ESP32 details
    Added detailed descriptions of the Arduino Nano and ESP32 functionalities, including their main functions and links to the respective code files.
2026-09-16 Enhance README with assembly and wiring details
    Added detailed sections for main chassis structure, complete assembly, steering component, and PCB & wiring implementation with images.
2026-09-16 Enhance README with detailed project documentation
    Expanded the README to include detailed sections on source code, power and sensor architecture, ultrasonic sensor expansion, wiring diagram, and PCB iteration problems.
2026-09-16 Enhance README with sensor details and calibration methods
    Expanded the README with detailed sections on sensor selection, placement, and calibration methods for the robot. Included specifics on the HC-SR04 ultrasonic sensors, MPU6050 IMU, and OpenMV H7 came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
2026-09-16 Enhance README with software architecture and strategies
    Expanded the README to include detailed sections on software architecture, state machine, open challenge algorithm, and vision processing strategy. Added information about the WS2812B RGB LED matrix 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
2026-09-16 Enhance README with vehicle evolution and analysis
    Added vehicle evolution section with before and after images, engineering decisions, risk analysis, wiring diagram, and components list.
2026-09-16 Create README.md for prototype development
    Added initial README.md for prototype documentation.
2026-09-16 Add README for additional project materials
2026-09-16 Update README with sensor code details
    Added sensor code references for ESP32 and Arduino Nano.
2026-09-18 Update image format for Real PCB in README
2026-09-18 Document final robot design and its advantages
    Added detailed explanation of the final robot design and its features, including reasons for design choices and benefits over previous prototypes.
